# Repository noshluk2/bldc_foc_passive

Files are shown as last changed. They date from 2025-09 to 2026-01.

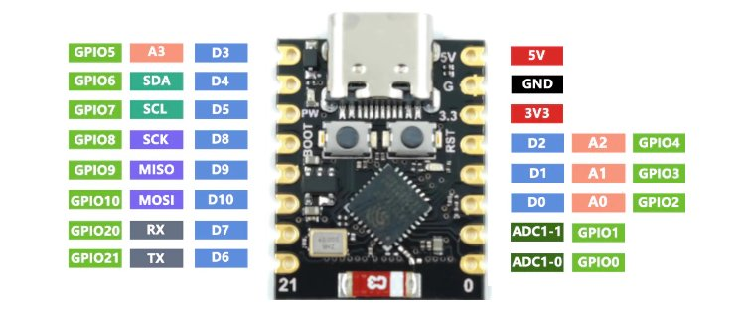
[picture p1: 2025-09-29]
resources/image.png

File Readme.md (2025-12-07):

### Features
- Overheating
- Pinned Wires
- Different power buses
- MicroController serial logging while powered on
- Current limiting and current sensing
- Heat decipation

### Problems
- Wires are alot of the motors , around each motor we have 9 wires so we are bringin in CAN communication to limit wires to only 4 ( 12V bus and Can Bus) with 2 of each. To pass through Hollow shaft.
- Holding torque with zero motion is always going to produce heat. As current have to convert to something else if not motion.
    - Al the very least we can add current sensing + shunts to measure current going in and hard cut that with a limit based on temperaure sensor on motor.
    - Link : https://chatgpt.com/share/68c27ee4-58ac-8005-99c9-39c60b1bd00c

### Tasks
[] - Variable Torque Resistance in motor
[] - Motor Attaing a positiong
[] - Reading Encoders precision
[] - Force Sensing
[] - Variable resistance upon force.

- Understanding thoery
    - kv , votlage, speed passive

-----
### Current Setup
- 4 gimbal axes (3× CubeMars GL30, 1× GL40)
- Each axis: Arduino Pro Mini + SimpleFOC, AS5048A (SPI) encoder
- One 12 V power bus and CAN (2-wire) daisy-chained through the hollow shafts

#### Future additions
- Add fuse + TVS + ≥470 µF at each joint’s 12 V entry.
- Confirm Pro Mini is 5 V (best with AS5048A). If 3.3 V, add SPI level shifting.
- Route E-STOP to the driver ENABLE so torque is killed in hardware; keep MCU + CAN powered.
- Place buck + logic away from the MOSFET switching node; keep encoder wires short and shielded.
- CAN: two terminators only; short stubs; twisted pair.
### Problems
1. Motors heating up on resistance :
    - Cause : Constant power supplied - need to limit unneccasry power applied to coils
    - Solution : Current limiting
1. Wire managment : cannot make all encoders + 12V buss wires throuh hollow shaft
    - solution researched : can bus

#### New Board Testing
- Udp Data Sending
    - /home/luqman/bldc_foc_passive/test/wifi/udp_test_sender.cpp -> ESP32
    - /home/luqman/bldc_foc_passive/test/wifi/udp_test_server.py -> PC

- Encoders testing
    - /home/luqman/bldc_foc_passive/test/encoders/read_encoders_udp.cpp
- Motor Driving testing
    - /home/luqman/bldc_foc_passive/test/motor/simple_drive.cpp

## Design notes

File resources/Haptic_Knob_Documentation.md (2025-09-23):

# Haptic Knob Implementation Documentation

## Overview
This document provides a comprehensive explanation of a haptic knob implementation using the SimpleFOC library to control a Brushless DC (BLDC) motor with a magnetic encoder. The system delivers a detent-like haptic feedback experience by combining damping torque and position-locking torque via a Proportional-Integral-Derivative (PID) controller. The code is designed for an Arduino-compatible microcontroller and leverages Field-Oriented Control (FOC) for precise motor control.

## Table of Contents
1. [System Architecture](#system-architecture)
2. [Key Concepts](#key-concepts)
3. [Code Structure and Workflow](#code-structure-and-workflow)
4. [Implementation Details](#implementation-details)
5. [Usage Instructions](#usage-instructions)
6. [Potential Enhancements](#potential-enhancements)
7. [Annotated Source Code](#annotated-source-code)

## System Architecture

### Hardware Components
- **BLDC Motor**: Configured with 7 pole pairs, controlled using FOC for smooth and efficient operation.
- **BLDCDriver3PWM**: A 3-phase PWM driver utilizing pins 26, 25, 33 (phase pins), and 32 (enable pin).
- **MagneticSensorSPI**: An AS5048 magnetic encoder connected via SPI (pins 14, 12, 13 for SCK, MISO, MOSI, and 27 for chip select) to provide high-resolution rotor angle and velocity feedback.
- **Microcontroller**: An Arduino-compatible board running the control loop and interfacing with the motor and sensor.

### Software Dependencies
- **SimpleFOC Library**: Facilitates FOC for BLDC motor control, handling phase commutation and sensor integration.
- **SPI Library**: Manages communication with the magnetic sensor.

## Key Concepts

### Field-Oriented Control (FOC)
FOC is an advanced motor control technique that aligns the stator's magnetic field with the rotor's magnetic field to maximize torque efficiency. The SimpleFOC library abstracts:
- **Phase Voltage Control**: Generates precise PWM signals for the motor's three phases.
- **Sensor Integration**: Utilizes encoder data to determine rotor position and velocity.

### Haptic Feedback Mechanism
The haptic knob delivers two distinct torque components:
1. **Damping Torque**: A velocity-proportional resistance that provides a consistent "heavy" feel during rotation.
2. **PID Torque**: Activates when the motor's velocity falls below a predefined threshold, locking the knob to a specific angle using a PID controller.

### PID Controller
The PID controller maintains the knob's position when locked:
- **Proportional Gain (P=30.00)**: Scales the torque response to the angular error.
- **Integral Gain (I=0.05)**: Compensates for steady-state error by accumulating error over time.
- **Derivative Gain (D=0.00)**: Disabled to avoid noise amplification in this application.
- **Output Constraints**: Limited to ±1000 units with a maximum voltage of 5V to ensure safe operation.

### Velocity Smoothing
A low-pass filter reduces noise in velocity measurements:
- **Filter Alpha (0.07)**: Determines the balance between responsiveness and noise suppression.
- **Formula**: `smoothed_velocity = (alpha * raw_velocity) + (1 - alpha) * smoothed_velocity`

### Angle Normalization
The `normalizeAngle` function constrains angle errors to the range [-π, π], ensuring the shortest-path correction for PID control.

## Code Structure and Workflow

### Initialization (setup)
- Configures serial communication (115200 baud) for debugging.
- Initializes SPI, sensor, driver, and motor.
- Sets FOC parameters: sine PWM modulation, torque control mode, and a 5V voltage limit.
- Initializes and enables the FOC algorithm.

### Main Loop (loop)
- Updates FOC calculations with `motor.loopFOC()`.
- Applies a low-pass filter to smooth velocity measurements.
- Computes damping torque continuously.
- Engages PID torque when velocity drops below 1 rad/s, locking the knob to the current angle.
- Combines torques and sends the command to the motor.
- Reports the shaft angle every 100ms via serial output.

### Helper Functions
- **normalizeAngle**: Normalizes angles to [-π, π] for accurate error calculation.
- **reportPosition**: Logs the motor's shaft angle at regular intervals.

## Implementation Details

### Parameter Configuration
- **Velocity Lock Threshold (1.00 rad/s)**: Determines when the position lock engages.
- **Base Damping Factor (0.05)**: Sets the strength of velocity-based resistance.
- **Filter Alpha (0.07)**: Controls velocity smoothing.
- **PID Parameters**: Tuned for stable and responsive position locking.

### Safety Features
- **Voltage Limit (5V)**: Prevents excessive torque, protecting the motor and hardware.
- **Velocity Threshold**: Ensures the lock disengages during intentional rotation, preventing abrupt resistance.

### Serial Reporting
- Position updates are sent every 100ms, providing real-time feedback for debugging and monitoring.

## Usage Instructions
1. **Hardware Setup**:
   - Connect the BLDC motor to the driver (pins 26, 25, 33, 32).
   - Wire the AS5048 sensor to SPI pins (14, 12, 13, 27).
   - Power the driver with a 12V supply.

2. **Software Setup**:
   - Install the SimpleFOC and SPI libraries in the Arduino IDE.
   - Upload the provided code to the microcontroller.

3. **Operation**:
   - Open the Serial Monitor (115200 baud) to view position updates.
   - Rotate the knob to experience damping and locking behavior.
   - Adjust parameters (e.g., PID gains, damping factor) to tune the haptic feel.

4. **Tuning Tips**:
   - Increase `base_damping_factor` for a heavier feel.
   - Adjust `velocity_lock_threshold` to change lock engagement sensitivity.
   - Modify PID gains for faster or smoother locking.

## Potential Enhancements
- **Detent Simulation**: Introduce periodic torque variations to mimic mechanical detents.
- **Dynamic Parameter Adjustment**: Implement serial commands to modify PID gains or damping in real time.
- **Error Handling**: Add checks for sensor or driver failures to improve robustness.
- **Multi-Position Locking**: Allow predefined lock points for a stepped haptic effect.

## Annotated Source Code

<xaiArtifact artifact_id="5ac701a3-345f-4305-a705-091431f37ada" artifact_version_id="0cb2e878-8303-416d-b880-5eef1b1e8f29" title="Haptic_Knob.ino" contentType="text/x-arduino">

#include <SimpleFOC.h>
#include <SPI.h>

// --- Hardware Configuration ---
// Instantiate 3-phase PWM driver with phase pins (A, B, C) and enable pin
BLDCDriver3PWM driver = BLDCDriver3PWM(26, 25, 33, 32);
// Define BLDC motor with 7 pole pairs for FOC calculations
BLDCMotor motor = BLDCMotor(7);
// Configure AS5048 magnetic encoder with SPI interface (CS pin 27)
MagneticSensorSPI sensor = MagneticSensorSPI(AS5048_SPI, 27);

// --- Haptic Feedback Parameters ---
// Target angle for position locking in radians
float target_angle = 0.0f;
// Flag indicating whether the motor is locked to a position
bool is_locked = false;
// Velocity threshold (rad/s) for engaging position lock
float velocity_lock_threshold = 1.00;
// Damping factor for velocity-proportional resistance
float base_damping_factor = 0.05;
// Low-pass filter coefficient for velocity smoothing
float filter_alpha = 0.07;
// Smoothed velocity to reduce noise and vibrations
float smoothed_velocity = 0.0f;

// --- PID Controller Configuration ---
// PID controller with P=30.0, I=0.05, D=0.0, ramp=1000, output limit=5.0V
PIDController pid_position(30.00, 0.05, 0.00, 1000, 5.0);

// --- Position Reporting Variables ---
// Timestamp of the last position report (milliseconds)
unsigned long last_report_time = 0;
// Interval for reporting position (milliseconds)
const int report_interval = 100;

// Forward declarations for helper functions
float normalizeAngle(float angle);
void reportPosition();

void setup() {
  // Initialize serial communication for debugging and monitoring
  Serial.begin(115200);
  // Configure SPI with custom pins (SCK=14, MISO=12, MOSI=13)
  SPI.begin(14, 12, 13);

  // Initialize magnetic sensor for rotor position feedback
  sensor.init();
  // Link sensor to motor for angle and velocity calculations
  motor.linkSensor(&sensor);
  // Set driver power supply voltage to 12V
  driver.voltage_power_supply = 12;
  // Initialize PWM driver
  driver.init();
  // Link driver to motor for phase control
  motor.linkDriver(&driver);

  // Configure FOC with sine PWM modulation and torque control mode
  motor.foc_modulation = FOCModulationType::SinePWM;
  motor.controller = MotionControlType::torque;
  // Set voltage limit to 5V for safe operation
  motor.voltage_limit = 5.0;

  // Initialize motor and FOC algorithm
  motor.init();
  motor.initFOC();
  // Enable motor control
  motor.enable();

  // Confirm initialization via serial output
  Serial.println("\n--- Haptic Knob Initialized ---");
}

void loop() {
  // Update FOC calculations for motor commutation and sensor reading
  motor.loopFOC();

  // --- Velocity Smoothing ---
  // Retrieve raw shaft velocity from motor
  float raw_velocity = motor.shaft_velocity;
  // Apply low-pass filter to smooth velocity and reduce noise
  smoothed_velocity = (filter_alpha * raw_velocity) + ((1.0 - filter_alpha) * smoothed_velocity);

  // --- Torque Calculation ---
  // Compute damping torque proportional to velocity for consistent resistance
  float damping_torque = -base_damping_factor * smoothed_velocity;

  // Initialize PID torque (active only when locked)
  float pid_torque = 0;
  // Check if velocity is below threshold to engage position lock
  if (abs(smoothed_velocity) < velocity_lock_threshold) {
    if (!is_locked) {
      // Engage lock by setting current angle as target
      target_angle = motor.shaft_angle;
      is_locked = true;
    }
    // Calculate normalized error between target and current angle
    float error = normalizeAngle(target_angle - motor.shaft_angle);
    // Compute PID torque to maintain position
    pid_torque = pid_position(error);
  } else {
    // Disengage lock when velocity exceeds threshold
    is_locked = false;
  }

  // --- Apply Combined Torque ---
  // Sum damping and PID torques for final motor command
  float total_torque = damping_torque + pid_torque;
  // Send torque command to motor
  motor.move(total_torque);

  // --- Periodic Position Reporting ---
  // Log shaft angle at regular intervals
  reportPosition();
}

/**
 * @brief Normalizes an angle to the range [-π, π] for shortest-path error calculation.
 * @param angle Input angle in radians.
 * @return Normalized angle in radians.
 */
float normalizeAngle(float angle) {
  float a = fmod(angle + PI, 2*PI);
  return a >= 0 ? (a - PI) : (a + PI);
}

/**
 * @brief Reports the motor's shaft angle to the Serial Monitor every 100ms.
 */
void reportPosition() {
  if (millis() - last_report_time > report_interval) {
    last_report_time = millis();
    Serial.print("Position [rad]: ");
    Serial.println(motor.shaft_angle);
  }
}

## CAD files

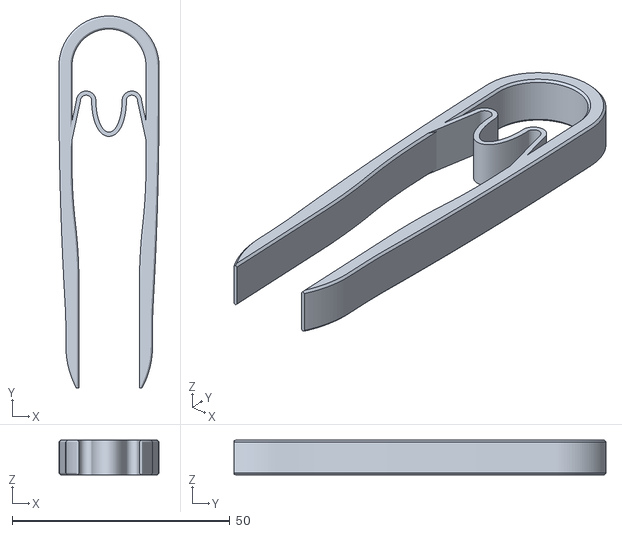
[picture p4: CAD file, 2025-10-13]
3d models/models/Tweezers.stl
23.0 x 85.5 x 8.00

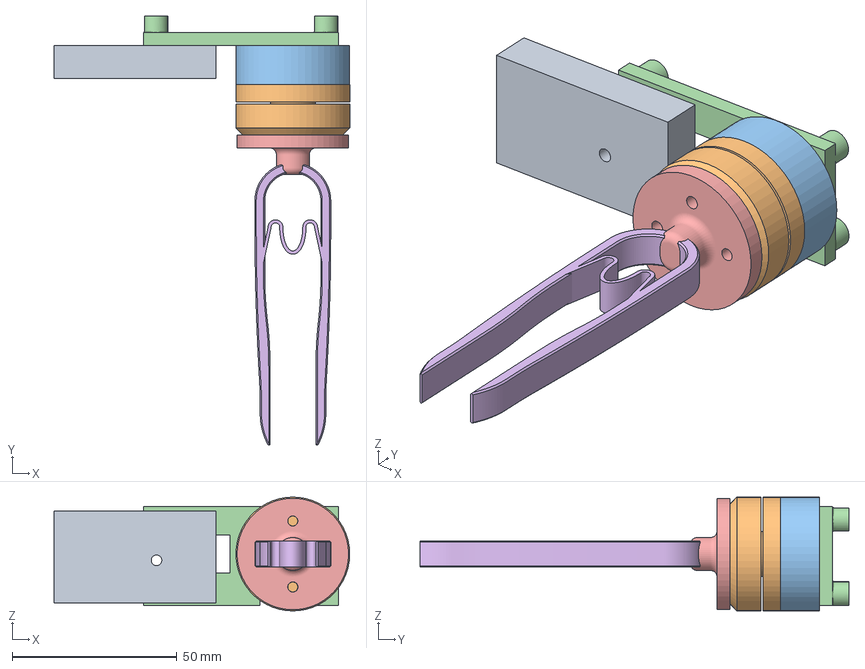
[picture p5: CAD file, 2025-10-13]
3d models/test_bench.FCStd
89.6 x 130.0 x 34.5 mm
circuit
GL30
encoder_cap
Tweezers

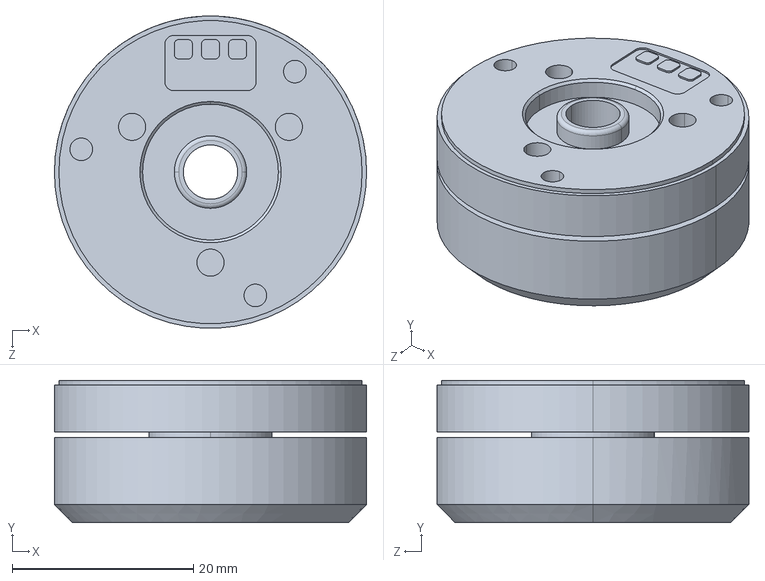
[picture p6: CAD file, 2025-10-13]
3d models/models/GL30.STEP
34.5 x 15.7 x 34.5 mm

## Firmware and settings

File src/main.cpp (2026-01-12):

#include <Arduino.h>


#include <Wire.h>

void setup() {
  Serial.begin(115200);
  delay(2000);

  Wire.begin(7, 8);          // SDA=7, SCL=8
  Wire.setClock(100000);     // Start conservative: 100 kHz

  Serial.println("I2C scan...");
    delay(2000);

  for (uint8_t addr = 1; addr < 127; addr++) {
    Wire.beginTransmission(addr);
    uint8_t err = Wire.endTransmission();
    if (err == 0) {
      Serial.printf("Found device at 0x%02X\n", addr);
    }
  }
  Serial.println("Done.");
}

void loop() {}

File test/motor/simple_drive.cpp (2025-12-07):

#include <Arduino.h>
#include <WiFi.h>
#include <WiFiUdp.h>
#include <stdarg.h>

// --------- Select which test pattern to run ----------
#define TEST_MODE 2   // 1 = original slow pattern, 2 = 2s fwd/stop/rev/stop

// --------- ESP32 <-> MCF8316A pins (your mapping) ----------
#define PIN_DIR      6
#define PIN_SPEED    9   // PWM-capable
#define PIN_DRVOFF   10
#define PIN_BRAKE    21
#define PIN_EXT_CLK  4
#define PIN_EXT_WD   18
#define PIN_SOX      17   // analog output from driver (optional)
#define PIN_I2C_SDA  7
#define PIN_I2C_SCL  8

// --------- WiFi / UDP config ----------
static const char* WIFI_SSID    = "Upper";
static const char* WIFI_PASS    = "786123786";
static const char* DEST_IP      = "192.168.1.4";  // your laptop IP
static const uint16_t DEST_PORT = 4444;           // UDP port on laptop

WiFiUDP udp;

// --------- UDP logging helper ----------
void udpLog(const char* fmt, ...) {
  if (WiFi.status() != WL_CONNECTED) return;

  char buf[160];
  va_list args;
  va_start(args, fmt);
  vsnprintf(buf, sizeof(buf), fmt, args);
  va_end(args);

  udp.beginPacket(DEST_IP, DEST_PORT);
  udp.write((const uint8_t*)buf, strlen(buf));
  udp.endPacket();
}

// --------- WiFi helper ----------
bool connectWiFi(uint32_t timeout_ms = 15000) {
  WiFi.mode(WIFI_STA);
  WiFi.persistent(false);
  WiFi.begin(WIFI_SSID, WIFI_PASS);

  uint32_t start = millis();
  while (WiFi.status() != WL_CONNECTED && (millis() - start) < timeout_ms) {
    delay(200);
  }
  if (WiFi.status() == WL_CONNECTED) {
    udp.begin(0);  // bind any local port
    IPAddress ip = WiFi.localIP();
    udpLog("BOOT: WiFi connected, IP=%u.%u.%u.%u\n", ip[0], ip[1], ip[2], ip[3]);
    return true;
  }
  return false;
}

// --------- PWM setup for SPEED pin ----------
static const int PWM_CHANNEL   = 0;
static const int PWM_FREQ_HZ   = 20000;  // 20 kHz
static const int PWM_RES_BITS  = 10;     // 0..1023
static const uint32_t PWM_MAX  = (1u << PWM_RES_BITS) - 1;

// speed levels
static const float SPEED_DUTY_FRACTION_SLOW   = 0.15f;  // 15% duty
static const float SPEED_DUTY_FRACTION_MEDIUM = 0.30f;  // 30% duty

static const uint32_t SPEED_DUTY_SLOW   = (uint32_t)(SPEED_DUTY_FRACTION_SLOW   * PWM_MAX);
static const uint32_t SPEED_DUTY_MEDIUM = (uint32_t)(SPEED_DUTY_FRACTION_MEDIUM * PWM_MAX);

// --------- simple state machine ----------
enum RunState {
  STATE_STOP1,
  STATE_FORWARD,
  STATE_STOP2,
  STATE_REVERSE
};

static RunState  state           = STATE_STOP1;
static uint32_t  state_start_ms  = 0;
static uint32_t  last_wifi_check = 0;

// helpers
static void setSpeedDuty(uint32_t duty) {
  if (duty > PWM_MAX) duty = PWM_MAX;
  ledcWrite(PWM_CHANNEL, duty);
}

static void setDirection(bool forward) {
  // polarity depends on wiring; adjust if reversed
  digitalWrite(PIN_DIR, forward ? LOW : HIGH);
}

// DRVOFF: HIGH = outputs off (coast), LOW = driver can drive motor
static void motorEnable(bool enable) {
  digitalWrite(PIN_DRVOFF, enable ? LOW : HIGH);
}

void setup() {
  // --- GPIO directions ---
  pinMode(PIN_DIR, OUTPUT);
  pinMode(PIN_SPEED, OUTPUT);
  pinMode(PIN_DRVOFF, OUTPUT);
  pinMode(PIN_BRAKE, OUTPUT);
  pinMode(PIN_EXT_CLK, OUTPUT);
  pinMode(PIN_EXT_WD, OUTPUT);
  pinMode(PIN_SOX, INPUT);  // driver analog out (we won't read it here)

  // --- Safe defaults ---
  motorEnable(false);             // keep OFF initially
  digitalWrite(PIN_BRAKE, LOW);   // no braking (depends on config)
  setDirection(true);             // default forward
  digitalWrite(PIN_EXT_CLK, LOW); // no external clock
  digitalWrite(PIN_EXT_WD, LOW);  // no watchdog tickle
  setSpeedDuty(0);                // 0% duty

  // --- WiFi connect ---
  connectWiFi(); // if it fails, we just won't see logs

  // --- PWM setup on SPEED pin ---
  ledcSetup(PWM_CHANNEL, PWM_FREQ_HZ, PWM_RES_BITS);
  ledcAttachPin(PIN_SPEED, PWM_CHANNEL);
  setSpeedDuty(0);

  delay(500); // let driver power up

  // enable driver (still 0% duty)
  motorEnable(true);
  udpLog("Motor driver enabled, TEST_MODE=%d\n", TEST_MODE);

  state = STATE_STOP1;
  state_start_ms = millis();
}

void loop() {
  uint32_t now = millis();
  uint32_t elapsed = now - state_start_ms;

  // Check WiFi every 5 seconds; if dropped, try reconnect
  if (now - last_wifi_check >= 5000) {
    last_wifi_check = now;
    if (WiFi.status() != WL_CONNECTED) {
      if (connectWiFi()) {
        udpLog("Reconnected to WiFi\n");
      }
    }
  }

  // ----- TEST_MODE 1: original slow pattern -----
#if TEST_MODE == 1
  switch (state) {
    case STATE_STOP1:
      // Motor stopped for 3 seconds, then go forward (slow)
      setSpeedDuty(0);
      setDirection(true);
      if (elapsed > 3000) {
        udpLog("[MODE1] FORWARD (slow)\n");
        state = STATE_FORWARD;
        state_start_ms = now;
        setSpeedDuty(SPEED_DUTY_SLOW);
      }
      break;

    case STATE_FORWARD:
      // Spin forward for 4 seconds, then stop
      if (elapsed > 4000) {
        udpLog("[MODE1] STOP (after forward)\n");
        state = STATE_STOP2;
        state_start_ms = now;
        setSpeedDuty(0);
      }
      break;

    case STATE_STOP2:
      // Stop 3 seconds, then reverse (slow)
      if (elapsed > 3000) {
        udpLog("[MODE1] REVERSE (slow)\n");
        state = STATE_REVERSE;
        state_start_ms = now;
        setDirection(false);
        setSpeedDuty(SPEED_DUTY_SLOW);
      }
      break;

    case STATE_REVERSE:
      // Spin reverse 4 seconds, then back to STOP1
      if (elapsed > 4000) {
        udpLog("[MODE1] STOP (after reverse), restarting cycle\n");
        state = STATE_STOP1;
        state_start_ms = now;
        setSpeedDuty(0);
        setDirection(true);  // reset to forward for next cycle
      }
      break;
  }

  // ----- TEST_MODE 2: 2s forward, stop, reverse, stop (medium speed) -----
#elif TEST_MODE == 2
  switch (state) {
    case STATE_STOP1:
      // Motor stopped for 2 seconds, then go forward (medium)
      setSpeedDuty(0);
      setDirection(true);
      if (elapsed > 2000) {
        udpLog("[MODE2] FORWARD (2s, medium speed)\n");
        state = STATE_FORWARD;
        state_start_ms = now;
        setSpeedDuty(SPEED_DUTY_MEDIUM);
      }
      break;

    case STATE_FORWARD:
      // Spin forward for 2 seconds, then stop
      if (elapsed > 2000) {
        udpLog("[MODE2] STOP (after forward)\n");
        state = STATE_STOP2;
        state_start_ms = now;
        setSpeedDuty(0);
      }
      break;

    case STATE_STOP2:
      // Stop 2 seconds, then reverse (medium)
      if (elapsed > 2000) {
        udpLog("[MODE2] REVERSE (2s, medium speed)\n");
        state = STATE_REVERSE;
        state_start_ms = now;
        setDirection(false);
        setSpeedDuty(SPEED_DUTY_MEDIUM);
      }
      break;
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

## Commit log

2025-09-29 wifi communication joint
2025-10-13 added 3d models + cogging scrpipts
    [GL30.STEP, Tweezers.stl, test_bench.FCStd]
2026-01-12 c3 and s3 i2c checking
